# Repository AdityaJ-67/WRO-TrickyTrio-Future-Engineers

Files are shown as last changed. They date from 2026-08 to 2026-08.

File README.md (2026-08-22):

<h1 align="center">Tricky Trio &middot; WRO 2026 Future Engineers</h1>

<!-- TODO: add a wide hero photo of the finished robot on the mat -->

---

## Table of Contents

1. [The Team](#1-the-team)
2. [Design Philosophy](#2-design-philosophy)
3. [Components](#3-components)
4. [Mobility and Mechanical Design](#4-mobility-and-mechanical-design)
5. [3D Models and Printed Parts](#5-3d-models-and-printed-parts)
6. [Power and Sensor Architecture](#6-power-and-sensor-architecture)
7. [Software Architecture](#7-software-architecture)
8. [Parking Strategy](#8-parking-strategy)
9. [Videos](#9-videos)
10. [Acknowledgements](#10-acknowledgements)

---

## Documentation Map

Detailed engineering documentation lives beside the work it describes.

| Topic | Document |
|---|---|
| Mobility and mechanical design, torque reasoning, trade-offs | [`models/mechanical-design.md`](models/mechanical-design.md) |
| Power budget, sensor selection and placement, calibration, failure points | [`schemes/power-and-sensors.md`](schemes/power-and-sensors.md) |
| Software architecture, flowcharts, obstacle strategy, testing | [`src/software-architecture.md`](src/software-architecture.md) |
| Constraints, trade-offs and risk analysis | [`other/engineering-journal/design-decisions.md`](other/engineering-journal/design-decisions.md) |
| How the subsystems work together | [`other/engineering-journal/systems-thinking.md`](other/engineering-journal/systems-thinking.md) |
| Every problem we hit and what we changed | [`other/engineering-journal/iteration-log.md`](other/engineering-journal/iteration-log.md) |
| Test records and calibration measurements | [`other/engineering-journal/test-logs.md`](other/engineering-journal/test-logs.md) |
| Building this robot from scratch | [`REPRODUCING.md`](REPRODUCING.md) |
| Line by line code walkthrough | [`other/code-explained.md`](other/code-explained.md) |
| Wiring and connection list | [`schemes/README.md`](schemes/README.md) |

---

## 1. The Team

<!-- TODO: add the photos to t-photos/ and check the filenames match -->

| | Who we are |
|---|---|
| <!-- TODO: photo --> | **Aditya Juneja**<br><br>A tenth grader with a long standing interest in computer science and robotics, Aditya was drawn to this project by the part of engineering where a plan on paper turns into something that actually moves. Away from the workshop he plays football, competes in track and field, and will usually be found teaching himself something new. |
| <!-- TODO: photo --> | **Ishayu Datta**<br><br>Ishayu is in tenth grade and came to the team through an interest in engineering, particularly in understanding why a design works rather than simply accepting that it does. Outside school he swims and plays guitar. |
| <!-- TODO: photo --> | **Sarjas Gauhar Singh**<br><br>Robotics and computer science are what pulled Sarjas into the project, though the hands on building is the part he enjoys most. Also in tenth grade, he plays guitar in bands and plays football. |
| <!-- TODO: photo --> | **Coach**<br><br>*To be filled in.* |

<p align="center">
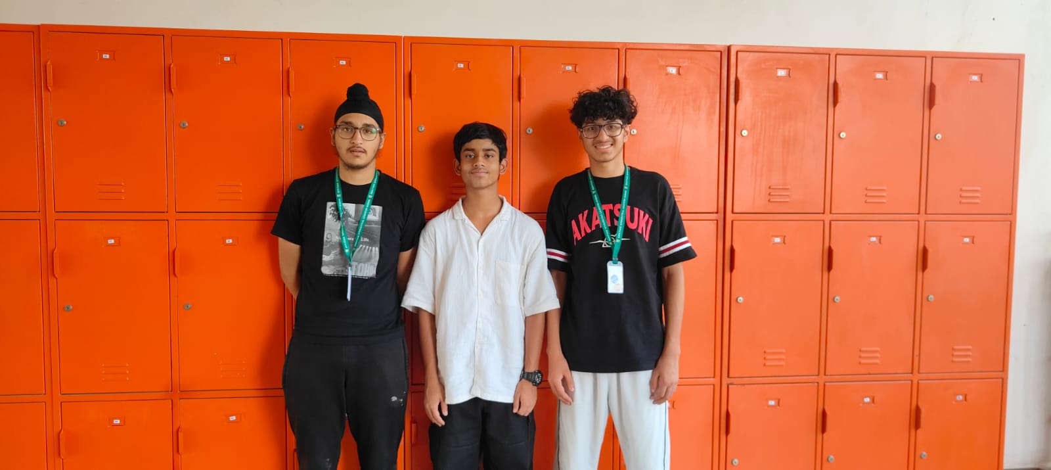
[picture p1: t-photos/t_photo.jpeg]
  
  &nbsp;
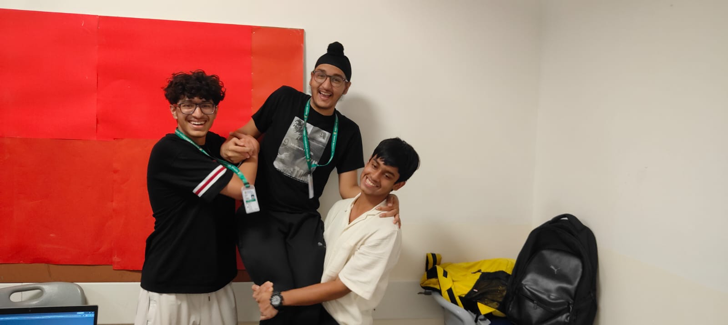
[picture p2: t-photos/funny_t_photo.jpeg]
  
</p>

**Country:** India &nbsp;&nbsp;&middot;&nbsp;&nbsp; **Team photos:** [`t-photos/`](t-photos/)

### What We Learned

**CAD and 3D design.** We designed the chassis, the steering assembly, the motor mount,
the battery holder and the wheels ourselves in Fusion 360, then printed and reprinted
them. Learning to design a part that can actually be printed, with the right tolerances
for a bearing or a screw, took several attempts per part.

**Electrical wiring and soldering.** We went from loose jumper wires to a planned
connection list and a proper PCB layout.

**Software architecture.** Writing code that a teammate can read months later turned
out to be a separate skill from writing code that works. We ended up splitting the
system into modules that each do one job, so a change to how the camera works cannot
break how the robot steers.

**Working as a team.** Three people editing the same project needed version control,
clear ownership of each subsystem, and the discipline to write down decisions instead
of remembering them.

---

## 2. Design Philosophy

Four principles we set before writing any code, and kept to. Every one of them exists
because of a specific problem we expected to hit.

**Split the work by timing requirement, not by convenience.**
The Raspberry Pi runs Linux, which is not a real time operating system. A background
process, a filesystem write or a Wi-Fi interrupt can stall a Python loop for tens of
milliseconds. That is invisible when you are processing a photo, and disastrous when a
servo is waiting for its next pulse. So the rule became: anything with a deadline runs
on the Pico, anything that needs to think runs on the Pi. The cost is a serial link
between them and the discipline of keeping a clear interface. What we get back is a
steering loop that cannot be interrupted by the camera.

**Make every module testable without the robot.**
Hardware is slow to test, easy to break, and often unavailable when you want to work.
So every file in this project runs a self test on a laptop with nothing plugged in. The
microcontroller modules are written so their hardware imports fail harmlessly off the
board, which leaves the maths behind them importable. This is why we could debug the
steering geometry and the orientation conversion weeks before the chassis was finished,
and why a change to one module tells us immediately if it broke another.

**Keep decisions in tables, not buried in conditionals.**
The robot's entire competition behaviour is one table of states and events. Anyone can
read what the robot does in each situation without following code paths through nested
if statements. When we improve how the robot detects a corner, we change how that event
is produced and the behaviour table never needs to know.

**Prefer something tunable over something optimal.**
A competition venue is a bad place to tune anything complicated. Where we had a choice
between a more sophisticated algorithm with several interacting constants and a simpler
one with a single gain, we took the simpler one. Being able to adjust the robot
confidently between rounds is worth more than a theoretically better response we cannot
reason about under pressure.

---

## 3. Components

<!-- TODO: add photos to v-photos/Components/ and fill any blank values.
     Blanks are values we have not measured or confirmed from a datasheet yet.
     Verify the filled figures against your own parts before relying on them. -->

### Raspberry Pi 3 Model B

<!-- TODO: photo -> v-photos/Components/pi3.jpg -->

**What it does.** Runs the camera and everything that needs to think: the vision
pipeline that finds traffic signs and parking markers, the navigation engine that
decides speed and steering, and the state machine that tracks what the robot is doing.
Chosen because computer vision needs an operating system, a filesystem and real RAM,
none of which a microcontroller has.

| Specification | Value |
|---|---|
| Processor | Broadcom BCM2837, quad core Cortex-A53 |
| Clock speed | 1.2 GHz |
| RAM | 1 GB LPDDR2 |
| Supply voltage | 5 V |
| Recommended supply current | 2.5 A |
| GPIO logic level | 3.3 V |
| Camera interface | 15 pin CSI-2 |
| Measured current draw, running vision | |

### Raspberry Pi Pico 2 W

<!-- TODO: photo -> v-photos/Components/pico.jpg -->

**What it does.** Runs everything with a deadline: the motor, the steering servo, the
wheel encoder and all six sensors. It also holds the safety watchdog, which stops the
robot if the Pi goes quiet for half a second.

| Specification | Value |
|---|---|
| Microcontroller | RP2350 |
| Cores | Dual Cortex-M33 |
| Clock speed | 150 MHz |
| SRAM | 520 KB |
| Flash | 4 MB |
| VSYS input range | 1.8 to 5.5 V |
| Logic level | 3.3 V, not 5 V tolerant |
| Measured current draw | |

### Camera Module 3

<!-- TODO: photo -> v-photos/Components/camera.jpg -->

**What it does.** The only sensor that can tell red from green, and the only one that
sees far enough ahead to plan a manoeuvre rather than react to one. It also finds the
magenta parking markers and the black wall.

| Specification | Value |
|---|---|
| Sensor | Sony IMX708 |
| Full resolution | 11.9 MP, 4608 x 2592 |
| Resolution used | 640 x 480 |
| Horizontal field of view | 66 degrees, standard lens |
| Focus | Autofocus |
| Connector | 15 pin FPC |
| Mounting height above mat | |
| Mounting angle | |

### GA12-N20 Gear Motor with Encoder

<!-- TODO: photo -> v-photos/Components/motor.jpg -->

**What it does.** Single drive motor on the rear axle. The built in encoder is the
important part: it lets us measure how far the wheels have actually turned, rather than
assuming the motor did what we asked. Without it the robot cannot tell that it is
stuck.

| Specification | Value |
|---|---|
| Rated voltage | 6 V |
| Encoder pulses per motor revolution | 7 |
| Gear ratio | |
| No load speed at the output shaft | |
| Stall torque | |
| Stall current | |
| Pulses per wheel revolution | |

### MG90S Servo

<!-- TODO: photo -> v-photos/Components/servo.jpg -->

**What it does.** Turns the front wheels through the Ackermann linkage. Metal geared,
so the gear train survives clipping a wall, which is what destroys plastic geared
servos.

| Specification | Value |
|---|---|
| Operating voltage | 4.8 to 6.0 V |
| Stall torque | 1.8 kg-cm at 4.8 V, 2.2 kg-cm at 6 V |
| Operating speed | 0.1 s per 60 degrees at 6 V |
| Gear material | Metal |
| Control signal | 50 Hz PWM |
| Pulse width range used | 1000 to 2000 microseconds |
| Steering range achieved | |

### DRV8833 Motor Driver

<!-- TODO: photo -> v-photos/Components/drv8833.jpg -->

**What it does.** Sits between the Pico and the motor. The Pico's pins can supply a few
milliamps; the motor needs hundreds. The driver takes a logic level signal and switches
the battery voltage across the motor, and it controls direction as well as speed.

| Specification | Value |
|---|---|
| Motor supply range | 2.7 to 10.8 V |
| Continuous current per channel | 1.5 A |
| Peak current per channel | 2 A |
| Logic input | 3.3 V compatible |
| PWM frequency used | 20 kHz |
| Control method | PWM on one input sets direction and speed |

### VL53L0X Time of Flight Sensor

<!-- TODO: photo -> v-photos/Components/vl53l0x.jpg -->

**What it does.** Four of these measure distance by timing a laser pulse. One faces
forward for corner detection, two face the forward diagonals for lane position, and one
faces backward. Unlike ultrasonic sensors they are unaffected by sound, and unlike the
camera they work regardless of colour.

| Specification | Value |
|---|---|
| Quantity | 4 |
| Measuring range | 30 to 2000 mm |
| Emitter | 940 nm VCSEL laser |
| Field of view | 25 degrees |
| I2C address | 0x29, fixed |
| Supply voltage | 3.3 V |
| Default timing budget | 33 ms per reading |
| Mounting angles | 0, minus 45, plus 45, 180 degrees |

### TCA9548A I2C Multiplexer

<!-- TODO: photo -> v-photos/Components/tca9548a.jpg -->

**What it does.** Solves a specific problem: every VL53L0X has the same fixed I2C
address, and so does the colour sensor. Put two on one bus and both answer at once. The
multiplexer connects one channel at a time, so each sensor gets the bus to itself.

| Specification | Value |
|---|---|
| Channels | 8 |
| Channels used | 6 |
| Address range | 0x70 to 0x77 |
| Address used | 0x70 |
| Supply voltage | 3.3 V |
| Bus speed used | 400 kHz |

### BNO085 IMU

<!-- TODO: photo -> v-photos/Components/bno085.jpg -->

**What it does.** Tells us which way the robot is pointing. This is how we know a
90 degree turn is finished, and how we hold a straight line between corners. It runs
sensor fusion on its own processor, so it hands over a finished orientation rather than
raw values to filter ourselves.

| Specification | Value |
|---|---|
| Sensors | 3 axis accelerometer, gyroscope and magnetometer |
| Output used | Rotation vector, as a quaternion |
| Supply voltage | 3.3 V |
| I2C address | 0x4A, or 0x4B if the jumper is bridged |
| Multiplexer channel | 2 |
| Polling rate used | 20 Hz |
| Heading accuracy | |

### TCS34725 Colour Sensor

<!-- TODO: photo -> v-photos/Components/tcs34725.jpg -->

**What it does.** Reads the colour of the mat directly underneath the car, which is how
we detect the orange and blue corner lines. Its built in infrared filter is why it stays
accurate while four infrared distance sensors are firing next to it.

| Specification | Value |
|---|---|
| Output channels | Red, green, blue and clear |
| Infrared filter | On die |
| Supply voltage | 3.3 V |
| I2C address | 0x29, fixed |
| Multiplexer channel | 1 |
| Gain options | 1x, 4x, 16x, 60x |
| Gain used | 4x |
| Integration time used | 50 ms |
| Mounting height above mat | |

### Mini560 Buck Converter

<!-- TODO: photo -> v-photos/Components/mini560.jpg -->

**What it does.** Steps the battery voltage down to a steady 5 V for the Pi, the Pico
and the servo. A buck converter rather than a linear regulator because it wastes far
less energy as heat, which matters when the Pi alone can draw over two amps.

| Specification | Value |
|---|---|
| Input voltage range | 4.5 to 20 V |
| Output voltage | 5 V |
| Maximum output current | 5 A |
| Efficiency | Up to 97 percent |
| Measured output under full load | |

### Battery

<!-- TODO: photo -> v-photos/Components/battery.jpg -->

**What it does.** Powers everything. Chosen for a high discharge rating, since the peak
draw when the servo hits full lock while the motor is accelerating is several times the
average.

| Specification | Value |
|---|---|
| Chemistry | 2S1P LiPo |
| Nominal voltage | 7.4 V |
| Capacity | 1500 mAh |
| Discharge rating | 35C |
| Stored energy | 11.1 Wh |
| Mass | |
| Measured run time | |

---

## 4. Mobility and Mechanical Design

### Chassis

| Property | Value | Why |
|---|---|---|
| Length | 15.0 cm | The parking slot is 1.5 times the robot length, so every centimetre of car costs 1.5 cm of slot. Short is safe. |
| Width | 10.5 cm | The lane is 100 cm wide. Narrow enough to pass a sign with margin either side. |
| Drive | Single motor, rear axle | The rules require the drive wheels to be physically connected. One motor through a gearbox satisfies this and removes differential speed error. |
| Steering | Ackermann, front axle, one servo | Required by the category focus on kinematics other than differential drive. |

### Why This Motor

The GA12-N20 was chosen for three reasons, in order of weight.

**The built in encoder was the deciding factor.** It lets us measure actual wheel
rotation instead of assuming that PWM duty maps cleanly to speed. Without odometry we
cannot detect a stalled robot, and stall detection is what triggers our recovery
behaviour. A robot that is wedged against a wall and does not know it will sit there
until the round ends.

Second, the integrated gearbox fits a package small enough for a 15 cm chassis. Third,
it runs at 6 V, matching the rest of the low voltage system.

**Torque and speed reasoning.** Theoretical top speed follows the relation between
wheel circumference and output shaft revolutions per minute. That figure ignores load,
rolling resistance and battery sag, so we treat it as an upper bound rather than a
target, and tune the operating speed experimentally instead.

<!-- TODO: measure these on the bench and fill them in. Do not estimate.
| Measurement | Value |
|---|---|
| Measured top speed, wheels off the ground | |
| Measured top speed, on the mat | |
| Lowest PWM percentage that actually moves the robot | |
| Time to travel 1 m from standstill | |
| Measured turning radius at full lock | |
-->

### Ackermann Steering

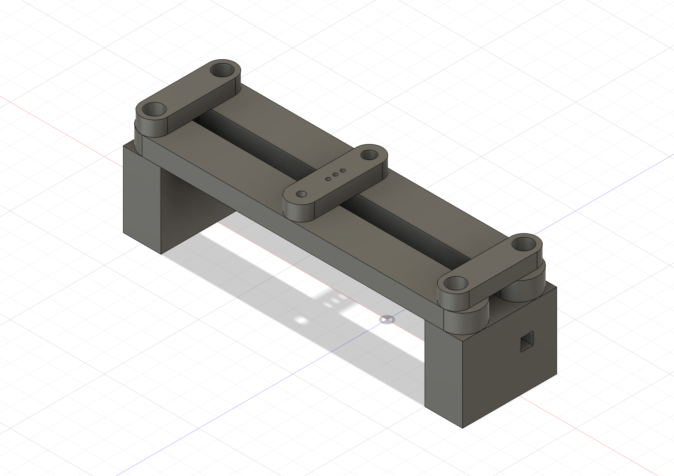
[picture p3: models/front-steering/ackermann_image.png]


We use an **Ackermann steering geometry** on the front axle, driven by a single servo
through a track rod.

The problem Ackermann solves is that when a car turns, the inside wheel travels a
tighter circle than the outside wheel. If both front wheels were held parallel, one of
them would have to scrub sideways through every corner, which wastes energy, wears the
tyre and makes the turn unpredictable. Ackermann geometry angles the steering arms so
the inside wheel turns through a **larger** angle than the outside one, letting both
wheels roll cleanly around a common centre.

For this robot that matters for two reasons. The corners are tight, so the difference
between the two wheel angles is significant rather than negligible. And our odometry
comes from the driven rear wheels, so anything that makes the front wheels scrub
introduces error into how far we think we have travelled.

The full assembly is in
[`models/front-steering/`](models/front-steering/) as a Fusion 360 file.

### Steering Control

The servo angle is converted to a pulse width from a calibrated centre position, with
three deliberate safety features.

The centre position is calibrated per build, because no two linkages sit neutral at the
same pulse width. A direction constant flips the sign if the servo is mounted mirrored,
so a mounting error is fixed with a constant rather than by negating in the code, and
the sign convention stays identical on both controllers.

Most importantly, the angle is clamped to plus or minus 30 degrees before conversion,
and the resulting pulse is clamped again to a safe range. A runaway command therefore
cannot drive the servo into the steering linkage and stall it. A stalled MG90S draws
over an amp and destroys its own gears in about a minute.

---

## 5. 3D Models and Printed Parts

Every structural part on this robot was designed by us and printed or fabricated in
house. Source files are in [`models/`](models/), organised by subsystem, each with the
CAD file and a render.

### Front Steering Assembly



Holds the two front wheels, the steering knuckles and the track rod that connects them
to the servo horn. The geometry of the steering arms is what produces the Ackermann
angle difference described above, so this part had the tightest tolerances of anything
we designed.

[`Ackerman System vinfinity.f3d`](models/front-steering/Ackerman%20System%20vinfinity.f3d)

### Rear Drive Mount

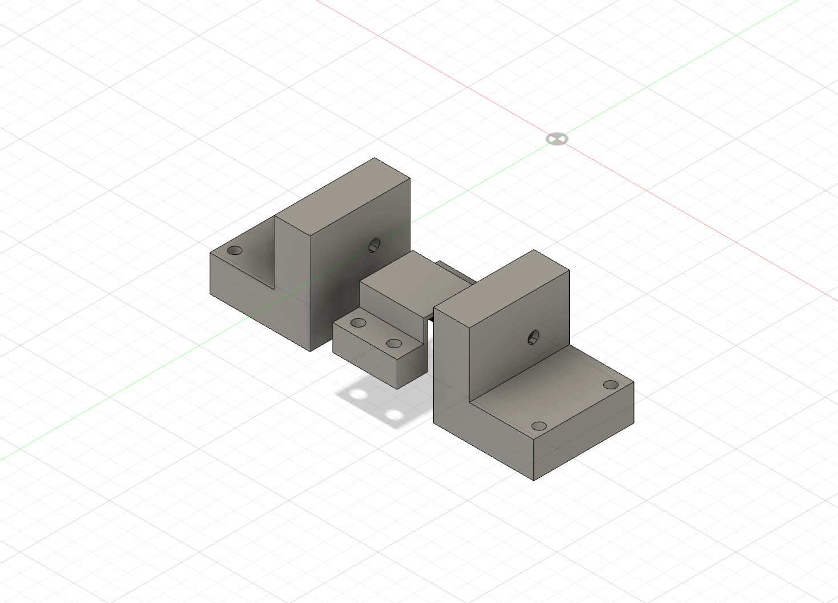
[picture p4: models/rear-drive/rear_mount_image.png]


Holds the GA12-N20 motor rigidly in line with the rear axle. Rigidity matters more than
it looks: any flex here shows up as inconsistent odometry, because the encoder counts
motor revolutions while the wheel is what actually moves the robot.

[`rear_motor_mount.step`](models/rear-drive/rear_motor_mount.step)

### Wheels

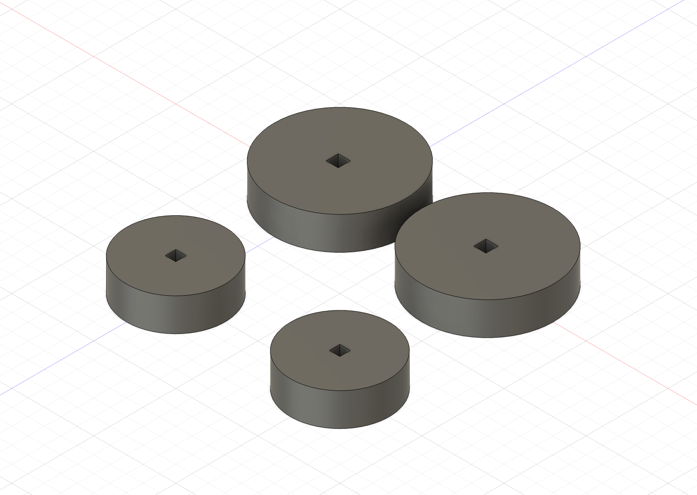
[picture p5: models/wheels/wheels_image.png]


Designed to a diameter that keeps the chassis low while giving enough ground clearance
for the mat. Wheel diameter feeds directly into every distance the robot calculates, so
this dimension is measured under load rather than taken from the model.

[`wheels.f3d`](models/wheels/wheels.f3d)

### Chassis Body

The body is printed in four sections so each fits the print bed and can be replaced on
its own without reprinting the whole car.

| Part | Render | Files |
|---|---|---|
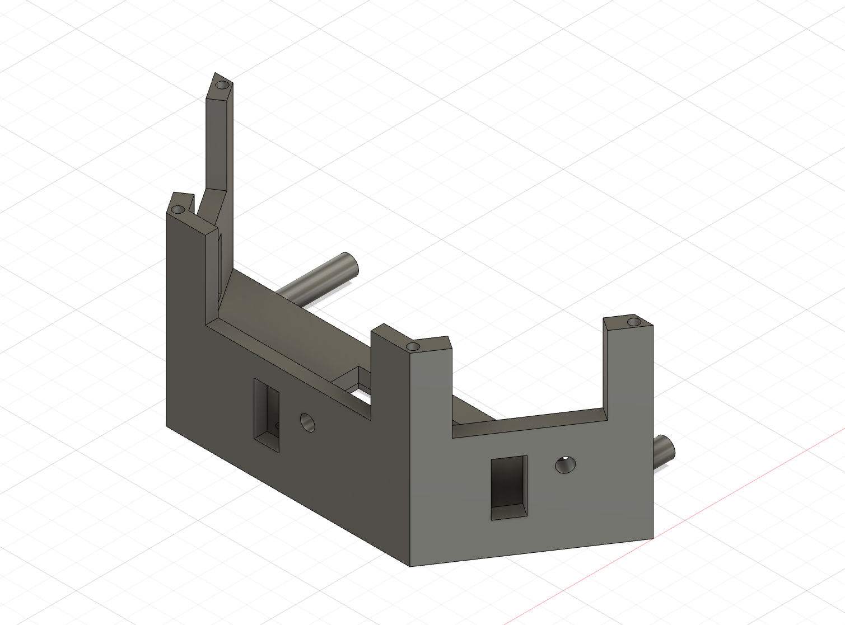
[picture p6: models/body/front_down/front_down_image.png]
| Front lower |  | [`front down.stl`](models/body/front_down/front%20down.stl) |
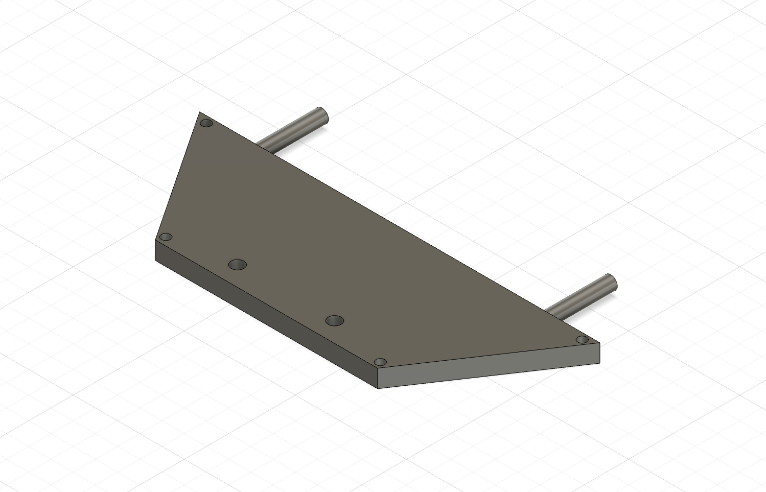
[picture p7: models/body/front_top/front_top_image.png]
| Front upper |  | [`front top.stl`](models/body/front_top/front%20top.stl) |
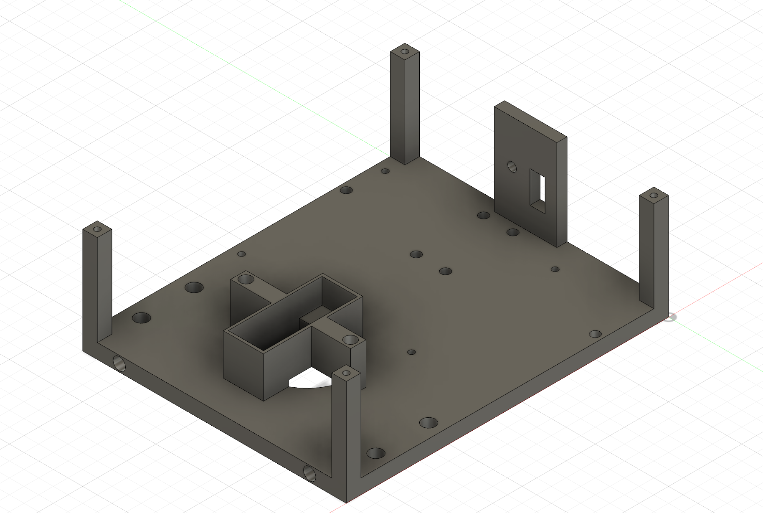
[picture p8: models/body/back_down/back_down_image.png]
| Rear lower |  | [`back down.stl`](models/body/back_down/back%20down.stl) |
| Rear upper | <!-- TODO: add back_top image and STL --> *to be added* | [`back_top/`](models/body/back_top/) |

### Camera Mount

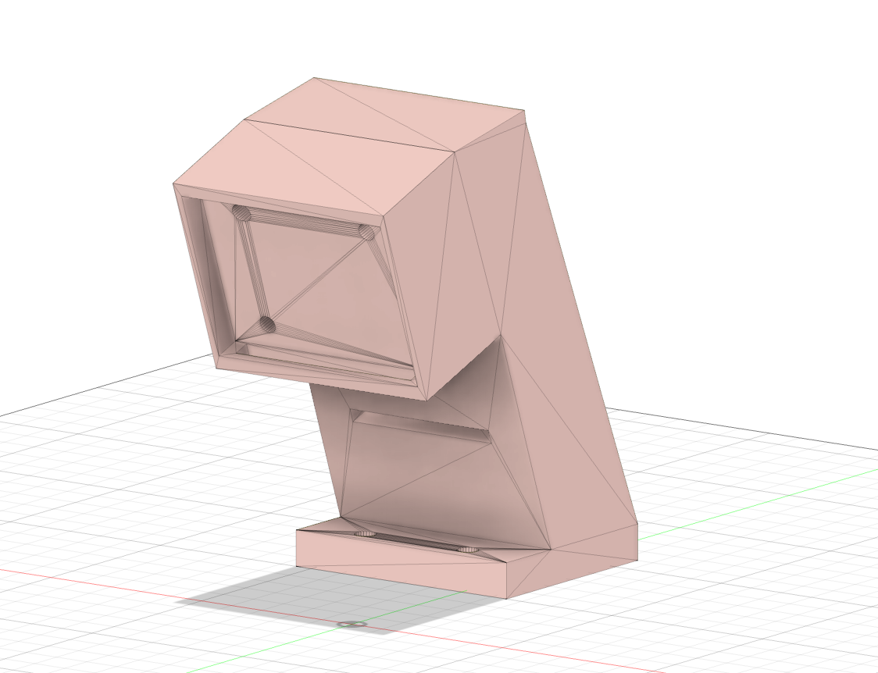
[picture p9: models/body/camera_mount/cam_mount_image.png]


Holds the camera at the front of the car, above the chassis. Height is the point of
this part: the further up the camera sits, the earlier it sees a traffic sign and the
more room the robot has to plan a way around it. The mount is rigid because the
distance estimate depends on how tall a sign appears in the frame, so a camera that
sags or vibrates reports the wrong range.

[`camera_mount.stl`](models/body/camera_mount/camera_mount.stl)

### Battery Mount

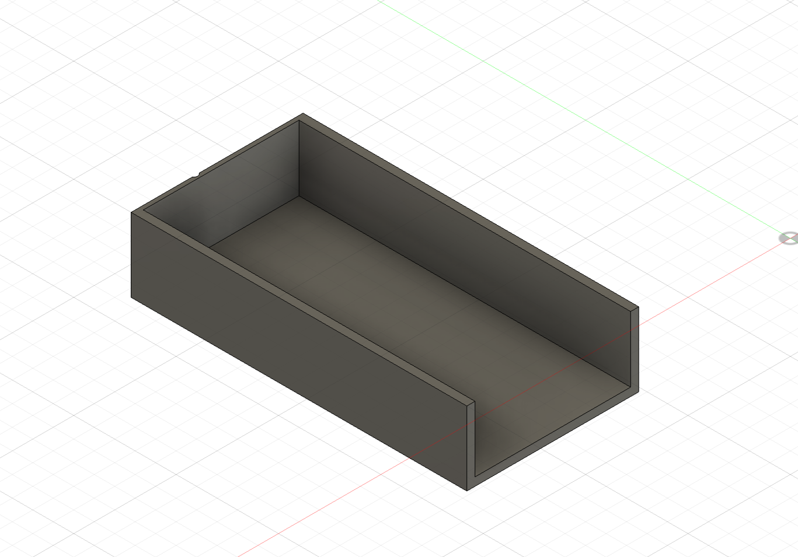
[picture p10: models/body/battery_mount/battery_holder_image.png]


Holds the LiPo low and central. Battery position affects weight distribution, which
affects how much grip the driven rear wheels have, so it is mounted as low as the
chassis allows.

[`battery_mount.stl`](models/body/battery_mount/battery_mount.stl)

<!-- TODO: worth adding if you have the information
| Print setting | Value |
|---|---|
| Material | |
| Layer height | |
| Infill | |
| Supports | |
-->

---

## 6. Power and Sensor Architecture

Wiring diagrams are in [`schemes/`](schemes/), with the complete master connection list
in [`schemes/README.md`](schemes/README.md).

### Power Budget

| Consumer | Typical | Peak | Notes |
|---|---|---|---|
| Raspberry Pi 3 | ~700 mA | ~2.5 A | Peaks during vision processing |
| MG90S servo | ~200 mA | ~1.5 A | Peak at stall or full lock |
| GA12-N20 motor | ~150 mA | ~800 mA | Peak at stall |
| Pico 2 W and sensors | ~150 mA | ~200 mA | Six I2C devices on the 3.3 V rail |
| **Total** | **~1.2 A** | **~5 A** | |

The peak figure is the one that matters. The Pi browns out and reboots if the 5 V rail
sags, and it sags exactly when the servo slams to full lock, which is precisely when
the robot is doing something difficult. Our mitigations are a 100 uF electrolytic
capacitor across the motor driver's supply pins at the driver itself, and a 0.1 uF
ceramic capacitor across the motor terminals to suppress brush noise.

### Sensor Placement



| Sensor | Quantity | Placement | Why here |
|---|---|---|---|
| Camera Module 3 | 1 | Front, elevated | Height gives earlier sight of signs, and it is the only sensor that distinguishes colour |
| VL53L0X | 1 | Front, 0 degrees | Corner confirmation and collision avoidance |
| VL53L0X | 2 | Plus and minus 45 degrees, flanking the camera | Lane position and corner geometry |
| VL53L0X | 1 | Rear, 180 degrees | Parking and reversing clearance |
| BNO085 | 1 | Rear of centre, mounted flat | Heading for turn completion and straight line hold |
| TCS34725 | 1 | Underside of the nose, below the camera mount | Corner line detection |

**The nose is a trapezoid**, and that shape exists to serve the sensors. Its three
faces each carry one distance sensor mounted perpendicular to that face, which is what
produces the 0 and plus or minus 45 degree angles without needing any brackets or
shims. A sensor sitting flat against a flat face is also far easier to align
repeatably than one held at an angle, and alignment matters because the readings are
compared against each other.

**The colour sensor sits at the very front, under the camera mount.** Putting it there
rather than under the middle of the car means the robot crosses a corner line with its
sensor before it crosses it with its wheels, which buys reaction time at exactly the
moment it is needed. It also shares the camera mount, so both sensors move together if
the mount is ever adjusted.

**The IMU sits toward the rear.** Heading is a property of the whole vehicle rather than
of a point on it, so a yaw reading is the same wherever the sensor is bolted. That frees
the IMU to go wherever there is flat, rigid space, which on this chassis is behind the
drive assembly, well away from the crowded nose.

**Why 45 degrees and not 90?** This is the placement decision we spent longest on.
Sensors pointing straight out to the sides tell you the lane width, but they only see a
corner once you are already level with it, which is too late to plan a turn. At 45
degrees they watch the forward diagonals, so an approaching inner wall shows up while
there is still room to react.

### Why a Multiplexer

Every VL53L0X ships with the same fixed I2C address, and so does the colour sensor. Put
two on one bus and both answer at once, and nothing in software can separate them.

There are two ways out. One is to pulse each sensor's shutdown pin at boot to bring
them up one at a time and reassign addresses. The other is to switch the bus. We chose
the TCA9548A multiplexer because it needs no extra GPIO pin per sensor and no boot time
sequencing that can fail silently.

| Multiplexer channel | Device |
|---|---|
| 0 | VL53L0X front |
| 1 | TCS34725 colour |
| 2 | BNO085 IMU |
| 3 | VL53L0X left |
| 4 | VL53L0X right |
| 5 | VL53L0X rear |

The cost is that reads are sequential: switch channel, talk, switch channel, talk. A
full sweep of four distance sensors costs about 132 ms, which is why the Pico applies
commands every 20 ms but sweeps sensors only every 150 ms. A single speed loop would
have delayed every motor command by the length of a sensor sweep.

---

## 7. Software Architecture

```
   +---------------- Raspberry Pi 3 ----------------+   +---- Pico 2 W ----+
   |                                                |   |                  |
   |  camera --> vision --> signs, wall, slot --+   |   |  motionController|
   |                                            |   |   |    servo         |
   |  robot_state --> mission --> navigation ---+   |   |    motor driver  |
   |                             (HOW to drive) |   |   |                  |
   |                          state machine ----+---+---+--> "45,23"       |
   |                          (WHAT we are doing)   |   |                  |
   |                                                |   |  sensorManager   |
   |  robot_state <---------------------------------+---+-- "S,480,230..." |
   +------------------------------------------------+   +------------------+
```

Each frame runs these seven steps, in this exact order.

| Step | What happens | Module |
|---|---|---|
| 1 | Capture a frame | `main.py` |
| 2 | Detect signs, wall and parking markers | `vision_test.py` |
| 3 | Read the newest robot state from the Pico | `main.py` |
| 4 | Ask which challenge is active | `mission_manager.py` |
| 5 | Decide **how** to drive, meaning speed and steering | `navigation_engine.py` |
| 6 | Decide **what** we are doing, and restrain the command | `state_machine.py` |
| 7 | Send the final command over UART | `main.py` |

**The separation that makes this work.** Navigation decides how to drive. The state
machine decides what we are doing, and it may only restrain navigation's request, never
invent one of its own. Cornering caps the speed lower than the straights. Recovery caps
it lower still. Finishing caps it to zero.

Only the coordinator writes to the serial port, and it writes only the state machine's
output, so there is exactly one place in the whole system where a command can reach the
wheels.

### The State Machine

**Twelve states, seventeen events, thirty transitions, three missions.**

The critical design choice is that detecting what happened is separate from deciding
what to do about it. One function turns sensor readings into named events, and it is
the only place that knows about millimetres and degrees. A separate table maps each
state and event to the next state, and that table contains no numbers at all.

Row order within the table is priority. When a wall and a sign are both visible, the
wall wins, and that is a line you can point at rather than a consequence of which if
statement happened to come first.

States: `WAIT_FOR_START`, `INITIALISE`, `FOLLOW_COURSE`, `APPROACH_PILLAR`,
`PASS_PILLAR`, `RECENTER`, `TURN_CORNER`, `SEARCH_PARKING`, `ALIGN_PARKING`,
`ENTER_PARKING`, `RECOVERY`, `FINISHED`.

### Vision Pipeline

Cost per frame is linear in the number of pixels and linear in the number of contours
found, and the pixel count is fixed by the processing width rather than the camera
resolution. The pipeline measures 0.32 ms per frame on a development laptop, which
means the camera frame rate is the ceiling rather than the code.

| Stage | Detail |
|---|---|
| Region of interest | Top 35 percent discarded, since only ceiling and lights live up there |
| Downscale | Detection runs at 320 pixels wide, drawing stays at full resolution |
| Colour threshold | Red needs two hue ranges because hue wraps around zero |
| Morphology | Open to remove speckle, close to fill glare holes |
| Contour filter | Area, aspect ratio and fill ratio together |

**Why the fill ratio matters.** Taking the largest contour locks onto a red jacket in
the audience or a stripe of glare on the mat. A real traffic sign fills its bounding
box, and scattered reflections do not. A candidate must pass area, aspect ratio and
fill ratio before it is believed.

**Distance from a single camera.** Signs are a known 10 cm tall, so the ratio of real
height to pixel height gives range without a stereo rig.

---

## 8. Parking Strategy

The parking lot is bounded by two magenta elements measuring 20 by 2 by 10 cm. The slot
is 20 cm wide and 1.5 times the robot's length, which for our 15 cm car means 22.5 cm.

### Magenta Against Red

Magenta sits immediately below red on the hue circle. Our original upper red band
started low enough that it **swallowed the magenta markers entirely**, and the robot
saw the parking lot as a giant traffic sign and tried to pass it on the right. The red
band now starts higher, which costs nothing because red's main band sits at the other
end of the scale.

### Aiming at the Gap

The vision module returns the midpoint between the markers' inner edges, which is the
slot itself rather than either marker. Both markers must be visible before the robot
commits, because you cannot aim at a gap you can only half see.

The sequence is `SEARCH_PARKING`, then `ALIGN_PARKING`, then `ENTER_PARKING`, then
`FINISHED`.

### Two Problems This Sequence Taught Us

**We were watching the wrong sensor.** Our first version stopped when the rear distance
sensor read close. But the camera faces forward, so the slot is only visible while
driving at it, meaning the robot enters nose first and the rear sensor is pointed back
at the open mat it came from. It never triggered, and the robot stopped on a timeout
rather than on arrival.

**The stop was then physically unreachable.** Navigation performs an emergency stop at
150 mm, but the parking trigger sat at 120 mm, so the robot froze before it could ever
reach its own trigger. The fix was a minimum speed for the entry phase, together with a
threshold below the emergency stop line, and a check that enforces that ordering so it
cannot silently break again.

---

## 9. Videos

<!-- TODO: replace with real links. Each video must show at least 30 seconds of
     autonomous driving, and one is required for each challenge. -->

| Round | Link |
|---|---|
| Open Challenge | *YouTube URL* |
| Obstacle Challenge | *YouTube URL* |

Also recorded in [`video/`](video/).

---

## 10. Acknowledgements

<!-- TODO: your school, mentors and sponsors -->

Open source work we build on: OpenCV, MicroPython, and the MicroPython drivers for the
VL53L0X, BNO08x and TCS34725 sensors. We also studied the public repositories of
previous WRO Future Engineers teams. The category's culture of publishing work openly
is the reason this repository exists in the form it does.

---

<p align="center">
  <b>Team Tricky Trio</b> &middot; India &middot; WRO 2026 Future Engineers
</p>

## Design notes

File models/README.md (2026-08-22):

# Models

**Design reasoning, torque and speed calculations, trade-offs and iterations are in
[mechanical-design.md](mechanical-design.md).**

CAD source files and renders for every part we designed and fabricated ourselves.
Organised by subsystem, one folder per part, each containing the model file and an
image of it.

| Folder | Part | Format |
|---|---|---|
| [`front-steering/`](front-steering/) | Ackermann steering assembly | Fusion 360 |
| [`rear-drive/`](rear-drive/) | Motor mount for the rear axle | STEP |
| [`wheels/`](wheels/) | Wheels | Fusion 360 |
| [`body/front_down/`](body/front_down/) | Front lower chassis section | STL |
| [`body/front_top/`](body/front_top/) | Front upper chassis section | STL |
| [`body/back_down/`](body/back_down/) | Rear lower chassis section | STL |
| [`body/back_top/`](body/back_top/) | Rear upper chassis section | STL |
| [`body/camera_mount/`](body/camera_mount/) | Camera mount | STL |
| [`body/battery_mount/`](body/battery_mount/) | Battery holder | STL |

The body is split into four printed sections so each fits the print bed and can be
reprinted on its own without redoing the whole car.

`.f3d` files are Fusion 360 sources and can be edited. `.stl` files are print ready
meshes. `.step` is a neutral CAD format that most packages can open.

See the main [README](../README.md) for how each part fits into the robot and why it is
shaped the way it is.

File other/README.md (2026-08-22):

# Other

Supporting material.

| Item | Contents |
|---|---|
| [`engineering-journal/`](engineering-journal/) | Design decisions, systems thinking, iteration log, test logs |
| [`code-explained.md`](code-explained.md) | Beginner level walkthrough of every source file |

<!-- TODO: this folder is currently empty. Worth adding:

       engineering-journal.pdf   The engineering journal, covering weekly progress,
                                 sketches, prototypes that did not work, and test logs.
                                 Judges evaluate this alongside the repository.

       datasheets/               Datasheets for the components, so anyone rebuilding
                                 the robot does not have to hunt for them.

       test-logs/                Records of bench and field testing. Dates, what was
                                 tested, what the numbers were, what changed as a
                                 result.

       calibration.md            The measured values for this particular build:
                                 gear ratio, wheel diameter under load, servo centre
                                 pulse, camera field of view, and the HSV colour
                                 ranges tuned on the competition mat. -->

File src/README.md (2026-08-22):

# Source Code

**Architecture, flowcharts, obstacle strategy and the testing process are in
[software-architecture.md](software-architecture.md).**

All software for the robot, split by the controller it runs on.

| Folder | Board | Language |
|---|---|---|
| [`pi3/`](pi3/) | Raspberry Pi 3 Model B | Python 3 with OpenCV |
| [`pico/`](pico/) | Raspberry Pi Pico 2 W | MicroPython |

## Why the split

The Raspberry Pi runs Linux, which is not a real time operating system. A background
process or a filesystem write can stall a Python loop for tens of milliseconds, which is
invisible when processing an image and disastrous when a servo is waiting for its next
pulse.

So the division is by timing requirement. Anything with a deadline runs on the Pico.
Anything that needs to think runs on the Pi. The two talk over a serial link: the Pi
sends a speed and steering command, the Pico sends back its sensor readings.

## Running the tests

Every module carries a self test that runs on a laptop with no hardware attached. The
MicroPython modules are written so their hardware imports fail harmlessly off the board,
which leaves the logic behind them testable.

```
cd src/pi3
python3 navigation_engine.py --selftest
python3 state_machine.py --selftest
```

Fifteen of the sixteen modules are covered. See each folder's README for detail.

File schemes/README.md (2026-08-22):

# Electrical Components and Wiring

## Contents

1. [System Architecture](#system-architecture)
2. [Component List](#component-list)
3. [Design Rationale](#design-rationale)
4. [Master Connection and PCB Routing List](#master-connection-and-pcb-routing-list)

---

## System Architecture

Compute is split across two boards. The **Raspberry Pi 3** is the high level brain,
handling anything that needs an operating system. The **Pico 2 W** is the low level
brainstem, handling anything with a deadline.

### What the Pi 3 is responsible for

**Computer vision.** The Camera Module 3 connects directly to the Pi 3, because
processing a live video feed needs the CPU, RAM and filesystem that a microcontroller
does not have. The Pi runs the detection pipeline that finds red and green traffic
signs, the black wall, and the magenta parking markers, and estimates the distance to
each from its known real height.

**Navigation and planning.** The Pi ingests the sensor readings the Pico sends over
UART, combines them with what the camera sees, and decides how to drive. Separate
steering laws handle lane following, sign passing, cornering and parking.

**Competition behaviour.** An event driven state machine tracks what the robot is
currently doing across twelve states and three missions, and has the final say on the
command that gets sent to the Pico.

**Telemetry.** During testing the Pi prints a status block per frame and can draw the
camera view with detections overlaid, which is how the vision thresholds get tuned.

### What the Pico 2 W is responsible for

Linux is not a real time operating system. A background process, a filesystem sync or a
Wi-Fi interrupt can stall a Python loop for tens of milliseconds, which is long enough
to make steering twitchy or leave a wheel spinning unchecked. The Pico runs a dedicated
loop instead, so these functions never get starved by the vision stack.

**Sensor harvesting.** The Pico manages the TCA9548A multiplexer, opening one channel
at a time to read the four distance sensors, the IMU and the colour sensor, then
packaging the readings into a single line of text and streaming it to the Pi.

**Actuation.** It generates the 50 Hz PWM the MG90S servo needs to hold a steering
angle without jitter, and the 20 kHz PWM that drives the DRV8833. The higher frequency
is above hearing, so the motor does not whine.

**Odometry.** The GA12-N20's encoder produces thousands of pulses per minute. The Pico
counts every one on a hardware interrupt, so pulses are never dropped even while the
main loop is busy elsewhere.

---

## Component List

<!-- TODO for each component:
       1. add a photo and fix the image path
       2. fill in the electrical values
     These are the ELECTRICAL specifications. Mechanical dimensions and
     performance figures live in the main README, so each number has one home. -->

### Raspberry Pi 3 Model B



| Specification | Value |
|---|---|
| Supply voltage | |
| Typical current draw | |
| Peak current draw | |
| Logic level | |
| Interface to Pico | |
| Camera interface | |

### Raspberry Pi Pico 2 W



| Specification | Value |
|---|---|
| Supply voltage (VSYS) | |
| Typical current draw | |
| Logic level | |
| 3.3 V rail output current available | |
| PWM channels used | |
| I2C bus used | |

### Camera Module 3



| Specification | Value |
|---|---|
| Supply | |
| Connector type | |
| Cable required for Pi 3 | |
| Resolution used | |
| Frame rate used | |

### GA12-N20 Gear Motor with Encoder



| Specification | Value |
|---|---|
| Rated voltage | |
| No load current | |
| Stall current | |
| Encoder supply voltage | |
| Encoder output type | |
| Encoder pulses per motor revolution | |

### MG90S Servo



| Specification | Value |
|---|---|
| Supply voltage | |
| Idle current | |
| Stall current | |
| Signal voltage accepted | |
| PWM frequency | |
| Pulse width range used | |

### DRV8833 Motor Driver



| Specification | Value |
|---|---|
| Motor supply (VM) range | |
| Continuous current per channel | |
| Peak current per channel | |
| Logic input voltage | |
| PWM frequency used | |
| nSLEEP handling | |

### VL53L0X Time of Flight Sensor (x4)



| Specification | Value |
|---|---|
| Supply voltage | |
| Current draw, per sensor | |
| I2C address | |
| Bus speed | |
| Multiplexer channels used | |
| XSHUT handling | |

### TCA9548A I2C Multiplexer



| Specification | Value |
|---|---|
| Supply voltage | |
| I2C address | |
| Number of channels | |
| Channels used | |
| Pull-up resistors fitted | |

### BNO085 IMU



| Specification | Value |
|---|---|
| Supply voltage | |
| Current draw | |
| I2C address | |
| Multiplexer channel | |
| Protocol select pins (PS0, PS1) | |

### TCS34725 Colour Sensor



| Specification | Value |
|---|---|
| Supply voltage | |
| Current draw | |
| I2C address | |
| Multiplexer channel | |
| Onboard LED control | |

### Mini560 Buck Converter



| Specification | Value |
|---|---|
| Input voltage range | |
| Output voltage | |
| Continuous output current | |
| Peak output current | |
| Efficiency | |

### Battery



| Specification | Value |
|---|---|
| Chemistry | 2S1P LiPo |
| Nominal voltage | 7.4 V |
| Capacity | 1500 mAh |
| Discharge rating | 35C |
| Stored energy | |
| Measured run time | |

---

## Design Rationale

Why these specific parts, rather than the alternatives.

### Compute and Control

Splitting compute across two boards was a deliberate choice rather than a default. A
single Pi could technically run everything, including the servo and motor PWM, but the
timing problem described above makes that unreliable in exactly the moments that
matter. Offloading motor control, encoder counting and the safety cutoff to the Pico
means those functions keep running no matter how busy the Pi gets processing camera
frames. The trade is extra wiring and a UART link to keep the two boards in sync, which
we accepted in exchange for control loops that never get starved.

### Drivetrain

The GA12-N20 6 V gearmotor was chosen for its combination of small size, integrated
gearbox and onboard encoder. **The encoder is the deciding factor.** It lets the Pico
measure actual wheel rotation instead of assuming a PWM duty cycle maps cleanly to
speed, and without it the robot cannot tell that it is stalled. Stall detection is what
triggers the recovery behaviour, so a robot without odometry that gets wedged against a
wall will sit there until the round ends.

Theoretical top speed follows the relation between wheel circumference and output shaft
revolutions per minute, but that ignores load, friction and battery sag, so we treat it
as a ceiling and tune the operating PWM experimentally instead.

The DRV8833 drives it, picked over bulkier options like the L298N for its smaller
footprint and much better efficiency at the low voltages this build runs at. It handles
both direction and speed while isolating the motor's current draw from the logic pins
on the Pico.

Steering uses the MG90S servo rather than a second drive motor or a rack and pinion
setup, since a servo gives direct, repeatable angle control in a small package. Its
signal comes straight from the Pico, so steering response stays independent of whatever
the Pi is doing with the camera feed. The metal gear train also survives clipping a
wall, which is the failure mode that destroys plastic geared servos.

### Power System

The robot runs on a 7.4 V, 1500 mAh, 35C, 2S1P LiPo, giving roughly 11 Wh of stored
energy.

One deliberate choice here: the DRV8833's motor supply taps the raw battery voltage
directly, in parallel with the buck converter's input, rather than running off the
regulated 5 V rail. That gives the motor more voltage headroom, at the cost of
overdriving a 6 V rated motor if it were ever run at 100 percent duty, which is why the
PWM duty is software limited rather than left uncapped. In exchange, motor current
never passes through the regulated logic rail at all, so current spikes cannot sag the
voltage feeding the Pi, the Pico or the sensors.

The Mini560 handles the regulated 5 V side that powers the Pi 3, the Pico and the
servo. The peak draw is what sizes it: the Pi alone can pull 2.5 A, and the servo adds
up to 1.5 A at stall, which happens exactly when the robot is steering hard.

### Logic Levels

**Every sensor output runs at 3.3 V.** The RP2350 is not 5 V tolerant, with an absolute
maximum of 3.3 V plus 0.3 V on any GPIO pin. This is why the N20 encoder is supplied
from the Pico's 3.3 V rail rather than the 5 V rail. A magnetic encoder outputs at
whatever voltage supplies it, so a 5 V supply would have put 5 V logic straight into
GP12 and GP13. That fault would have worked on the bench and destroyed the
microcontroller days later, which is the hardest kind of fault to diagnose because it
looks like a software bug.

### Sensor Placement



### Distance and Environmental Sensing

Four VL53L0X time of flight sensors sit across the front and back of the chassis rather
than one, so the robot gets several simultaneous readings across its field of travel
instead of a single point measurement.

The front of the chassis is a trapezoid, and its three faces each carry one sensor
mounted perpendicular to that face. That geometry is what produces the 0 and plus or
minus 45 degree angles directly, with no brackets or shims, and a sensor sitting flat
against a flat face aligns far more repeatably than one held at an angle. The two
angled sensors therefore watch the forward diagonals and see an approaching corner
while there is still room to react.

All VL53L0X units share the same default I2C address, and so does the TCS34725, which
is a problem the moment you want more than one on a bus. Rather than reflashing each
sensor's address individually, a TCA9548A multiplexer sits between the Pico and the
sensor network, giving each device its own isolated channel. That uses six of the eight
channels, leaving two free for future additions without rewiring anything.

### Orientation and Colour Sensing

The BNO085 IMU adds orientation data that neither the encoder nor the camera can
provide on their own, and it is particularly useful mid turn, where wheel odometry
alone drifts. It runs sensor fusion on its own processor rather than handing over raw
accelerometer and gyroscope values to filter.

The TCS34725 exists so that colour detection does not depend entirely on the camera. It
gives a direct, low overhead reading that the Pico can act on quickly, while the camera
handles the spatial side of track interpretation on the Pi. Its built in infrared filter
is what keeps it stable while four infrared distance sensors are firing beside it.

It is mounted on the underside of the nose, directly below the camera mount. Sitting at
the front rather than under the middle of the car means the sensor crosses a corner line
before the wheels do, which gives the robot more time to react. Sharing the camera mount
also means the two front facing sensors stay aligned with each other.

The IMU, by contrast, sits toward the rear. Yaw is a property of the whole vehicle
rather than of a point on it, so the heading reading is the same wherever the sensor is
mounted. That let us put it where there was flat, rigid space, behind the drive assembly
and away from the crowded nose.

### Vision System

The Camera Module 3 is the primary visual sensor and the only one that can distinguish
red from green. It is also the only sensor that sees far enough ahead to plan a
manoeuvre rather than react to one.

The Pi 3 has a single 15 pin CSI connector, so the camera uses a standard 15 pin ribbon
cable. The 15 to 22 pin adapter sold for Camera Module 3 is for the newer boards with
narrower connectors and does not fit a Pi 3.

---

## Master Connection and PCB Routing List

> Header pins referenced below (2/4 = 5V, 6 = GND, 8 = GPIO14/TXD, 10 = GPIO15/RXD)
> are identical across all 40-pin Raspberry Pi boards.

### 1. Power Distribution Bus
- Battery Positive (+) ➡️ Mini560 IN(+) AND DRV8833 VM (Motor Power Input).
- Battery Negative (-) ➡️ Mini560 IN(-) (Establishes the main system GND rail).
- Mini560 OUT(+) [5V Rail] ➡️ Pico 2 W Pin 39 (VSYS) AND Pi 3 Pin 2/4 (5V) AND MG90S Servo Red (VCC).
  - **The N20 encoder must NOT sit on this rail.** Its A/B outputs swing to whatever voltage supplies it, and the RP2350 GPIOs are not 5V tolerant (absolute max 3.3V + 0.3V). Encoder VCC goes to the 3V3 rail below.
- Mini560 OUT(-) [GND Plane] ➡️ Pico Pin 38 (GND) AND Pi 3 Pin 6 (GND) AND Servo Brown (GND) AND Encoder GND AND DRV8833 GND. Flood the entire bottom layer of the PCB as a solid ground plane to connect these seamlessly.
- Pico Pin 36 (3V3 OUT Rail) ➡️ VCC / VIN pins of the TCA9548A, BNO085, TCS34725, and all 4x VL53L0X sensors, **plus N20 Encoder VCC and DRV8833 nSLEEP**.
  - Encoder VCC here, not on 5V, so the A/B outputs are 3.3V logic. It draws a few mA.
  - nSLEEP (labelled SLP or EEP on most breakouts) must be high or the driver stays asleep and the motor does nothing while the code reads perfectly correct. Some breakouts pull it high on-board, so check yours before adding the trace.
- **Decoupling:** 100 µF electrolytic across DRV8833 VM/GND, placed at the driver. Motor current spikes otherwise drag the shared 5V rail down far enough to reset the Pico mid-run.

### 2. High-Level Logic Interconnects
- Pico Pin 1 (GP0 / TX) ➡️ Pi 3 GPIO Pin 10 (RXD0 / GPIO 15)
- Pico Pin 2 (GP1 / RX) ➡️ Pi 3 GPIO Pin 8 (TXD0 / GPIO 14)
  - Pi 3 only: `/dev/serial0` defaults to the mini-UART, whose baud rate drifts with CPU load and corrupts bytes once the vision code is running. Set `enable_uart=1` and `dtoverlay=disable-bt` in config.txt, then confirm `ls -l /dev/serial0` resolves to **ttyAMA0**, not ttyS0.
- Camera Module 3 ➡️ Connects directly to the Pi 3's single 15-pin CSI port via a standard 15-pin ribbon cable. The 15-to-22 pin cable is for the newer boards with narrower connectors and does not fit a Pi 3. (Does not wire to the Pico 2 W.)

### 3. Sensor I2C Network
- Pico Pin 6 (GP4 / SDA) ➡️ TCA9548A SDA (add a 4.7kΩ pull-up resistor to the 3.3V trace).
- Pico Pin 7 (GP5 / SCL) ➡️ TCA9548A SCL (add a 4.7kΩ pull-up resistor to the 3.3V trace).
- TCA9548A CH0 (SD0 / SC0) ➡️ VL53L0X Distance Sensor #1 (SDA / SCL)
- TCA9548A CH1 (SD1 / SC1) ➡️ TCS34725 Color Sensor (SDA / SCL)
- TCA9548A CH2 (SD2 / SC2) ➡️ BNO085 IMU Sensor (SDA / SCL)
- TCA9548A CH3 (SD3 / SC3) ➡️ VL53L0X Distance Sensor #2 (SDA / SCL)
- TCA9548A CH4 (SD4 / SC4) ➡️ VL53L0X Distance Sensor #3 (SDA / SCL)
- TCA9548A CH5 (SD5 / SC5) ➡️ VL53L0X Distance Sensor #4 (SDA / SCL)
- Note: leave all VL53L0X XSHUT pins completely disconnected on the PCB, since they pull high naturally.

### 4. Drivetrain Control (Motors, Encoders, & Servos)
- Pico Pin 29 (GP22) ➡️ MG90S Servo Orange (Signal Pin). Bypasses the driver entirely.
- Pico Pin 11 (GP8) ➡️ DRV8833 IN1 (Motor Drive Forward PWM)
- Pico Pin 12 (GP9) ➡️ DRV8833 IN2 (held low for forward; carries the PWM for reverse)
  - A DRV8833 has no dedicated direction pin. Whichever of IN1/IN2 carries the PWM is the direction, and the duty on it is the speed. GP8 and GP9 are the two halves of PWM slice 4, so they share a frequency, which suits reverse fine since both want the same 20 kHz.
- DRV8833 OUT1 / OUT2 ➡️ GA12-N20 Motor Pin 1 & Pin 2 (Motor Power Leads)
  - Solder a 0.1 µF ceramic across the two motor terminals. Brush noise otherwise couples into the encoder lines and shows up as phantom counts that appear only under motor power.
- GA12-N20 Motor Pin 5 (Encoder A) ➡️ Pico Pin 16 (GP12)
- GA12-N20 Motor Pin 6 (Encoder B) ➡️ Pico Pin 17 (GP13)
  - Route both encoder traces away from the thick motor leads, for the same reason.

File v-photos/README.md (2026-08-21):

# Vehicle Photos

Photographs of the assembled robot.

## Required

Six photographs of the vehicle are required: from every side, from the top, and from the
bottom.

<!-- TODO: add these six, with these filenames:

       front.jpg
       back.jpg
       left.jpg
       right.jpg
       top.jpg
       bottom.jpg

     A plain background and even lighting is enough. Fill the frame with the robot.
     The bottom view matters more than it sounds: it is the one that shows the
     drivetrain, the steering linkage and the sensor mounting. -->

## Subfolders

| Folder | Contents |
|---|---|
| [`Components/`](Components/) | Individual photographs of each electronic component |
| [`build-progress/`](build-progress/) | Photographs taken during the build |

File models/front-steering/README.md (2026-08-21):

# Front Steering Assembly



The Ackermann steering assembly. Holds both front wheels, the steering knuckles, and
the track rod that links them to the servo horn.

**Why Ackermann.** When a car turns, the inside wheel follows a tighter circle than the
outside wheel. Holding both front wheels parallel would force one of them to scrub
sideways through every corner, wasting energy, wearing the tyre and making the turn
unpredictable. Ackermann geometry angles the steering arms so the inside wheel turns
through a larger angle than the outside one, letting both roll cleanly around a shared
turning centre.

That matters here for two reasons. The corners on this course are tight, so the
difference between the two wheel angles is significant rather than negligible. And our
odometry comes from the driven rear wheels, so anything that makes the front wheels
scrub introduces error into how far the robot thinks it has travelled.

This part had the tightest tolerances of anything we designed, since the steering arm
geometry is what produces the angle difference.

| File | Format | Notes |
|---|---|---|
| `Ackerman System vinfinity.f3d` | Fusion 360 | Editable source |

<!-- TODO: fill in
| Property | Value |
|---|---|
| Material | |
| Layer height | |
| Infill | |
| Steering range achieved | |
-->

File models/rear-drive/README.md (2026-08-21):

# Rear Drive Mount



Holds the GA12-N20 gear motor rigidly in line with the rear axle.

**Why rigidity matters more than it looks.** The encoder counts revolutions of the
motor shaft, but what actually moves the robot is the wheel. Any flex or play between
the two shows up as a mismatch between the distance the robot calculates and the
distance it travels. Since our navigation uses that distance to judge how far it has
gone, a soft mount quietly degrades everything downstream.

| File | Format | Notes |
|---|---|---|
| `rear_motor_mount.step` | STEP | Neutral CAD format, opens in most packages |

<!-- TODO: fill in
| Property | Value |
|---|---|
| Material | |
| Layer height | |
| Infill | |
| Fasteners used | |
-->

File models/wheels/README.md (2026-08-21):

# Wheels



Custom wheels, sized to keep the chassis low while leaving enough ground clearance for
the mat surface.

**Why the diameter is a measured value, not a design value.** Wheel diameter feeds
directly into every distance the robot calculates, because distance travelled is
revolutions multiplied by circumference. Rubber compresses under load, so the rolling
diameter is always slightly smaller than the modelled one. We measure it with the
robot's weight on the wheels and use that figure in the code, rather than taking the
number from the CAD file.

| File | Format | Notes |
|---|---|---|
| `wheels.f3d` | Fusion 360 | Editable source |

<!-- TODO: fill in
| Property | Value |
|---|---|
| Modelled diameter | |
| Measured rolling diameter, under load | |
| Material | |
| Tyre material | |
| Layer height | |
| Infill | |
-->

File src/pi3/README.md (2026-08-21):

# Raspberry Pi 3 Source

Python 3 with OpenCV. Everything here needs an operating system: the camera, the vision
pipeline, and the decisions about where to drive.

## Files

| File | What it does |
|---|---|
| `main.py` | The control loop. Coordinates the other modules and owns the serial link. Contains no decision logic of its own. |
| `camera_vision/vision_test.py` | Detects red and green traffic signs, the black wall and the magenta parking markers, and estimates the distance to each. |
| `navigation_engine.py` | Decides how to drive. Separate steering laws for lane following, sign passing, cornering and parking. |
| `state_machine.py` | Decides what the robot is currently doing, across twelve states and three missions. Has the final say on the command sent to the Pico. |
| `mission_manager.py` | Reports which challenge is active. |
| `uart_test_pi.py` | Bench tool for testing the serial link on its own. |

## The loop

Each camera frame runs the same seven steps in the same order: capture, detect, read the
robot's state from the Pico, check the mission, decide how to drive, decide what we are
doing, send one command.

The separation that makes this work is that the navigation engine decides *how* to drive
while the state machine decides *what* we are doing, and the state machine may only
restrain navigation's request rather than invent one of its own. Only `main.py` writes
to the serial port, so there is exactly one place a command can reach the wheels.

## Running it

```
python3 main.py                    competition
python3 main.py --dry-run --show   laptop: webcam and decisions, no Pico
python3 main.py --debug            one status block per frame
```

On a Raspberry Pi 3 the serial port needs moving off the mini UART first, otherwise it
corrupts bytes under processor load. See [`schemes/README.md`](../../schemes/README.md).

## Testing

```
python3 navigation_engine.py --selftest
python3 state_machine.py --selftest
```

Every module has one, and they all run with no hardware attached.

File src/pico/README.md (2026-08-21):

# Pico 2 W Source

MicroPython. Everything here has a deadline: the motor, the steering servo, the wheel
encoder and the six sensors.

## Files

| File | What it does |
|---|---|
| `main.py` | Flight program. Reads commands, drives the robot, reports sensor state. Runs automatically on power up. |
| `motionController.py` | One interface for movement: `move(speed, steering)` and `stop()`. |
| `servo.py` | MG90S steering, with clamped angle and pulse limits. |
| `drv8833.py` | Drive motor through the DRV8833. |
| `encoder.py` | Wheel odometry from the quadrature encoder, counted on an interrupt. |
| `sensors/sensorManager.py` | Gathers every sensor reading into one dictionary. |
| `sensors/distance.py` | Four VL53L0X distance sensors behind the multiplexer. |
| `sensors/imu.py` | BNO085 orientation. |
| `sensors/colour.py` | TCS34725 floor colour. |
| `uart_echo.py` | Bench tool for testing the serial link on its own. |
| `deploy.sh` | Copies everything to the board. |

## The loop

The flight program runs at two speeds on purpose. Commands are read and applied every
20 ms, because a command that waits is a robot that has already driven somewhere else.
A full sweep of the four distance sensors costs about 130 ms, so that happens on its own
slower schedule and never delays the motor.

If no command arrives for 500 ms, meaning the Pi has crashed or the cable has come
loose, the watchdog stops the robot. This is the main reason the control system is split
across two boards.

## Deploying

MicroPython has no package imports here, so every file lands flat at the board's root
regardless of the folders used in this repository.

```
./deploy.sh              copy the flight code
./deploy.sh --drivers    also copy the sensor drivers
```

<!-- TODO: the sensor drivers are not in this repository yet. The modules import
     vl53l0x, tcs34725 and bno08x by name. Without them the sensors will not read,
     though each module reports which file is missing and the robot keeps running. -->

## Testing

```
python3 -c "import servo; servo.selftest()"
```

Each module's self test runs on a laptop with no board attached.

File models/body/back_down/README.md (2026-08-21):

# Rear Lower Chassis Section



The lower rear section of the body. Carries the drive motor mount and the rear axle,
and forms the rear floor of the car.

All drive torque is reacted through this part, so it is stiff for the same reason the
motor mount is: any flex between the motor and the wheels shows up as odometry error.

| File | Format |
|---|---|
| `back down.stl` | STL, print ready |

<!-- TODO: fill in
| Property | Value |
|---|---|
| Material | |
| Layer height | |
| Infill | |
| Print time | |
-->

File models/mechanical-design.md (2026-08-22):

# Mechanical Design and Mobility

Chassis design choices, drive and steering justification, torque and speed reasoning,
and the iterations that changed the design.

Covers rubric criterion 1. Part files and renders are in the subfolders of this
directory; this document explains why they are shaped the way they are.

## Contents

1. [Design Constraints](#design-constraints)
2. [Chassis](#chassis)
3. [Drive System](#drive-system)
4. [Torque and Speed Reasoning](#torque-and-speed-reasoning)
5. [Steering System](#steering-system)
6. [Mechanical Stability](#mechanical-stability)
7. [Trade-offs](#trade-offs)
8. [Iterations](#iterations)

## Design Constraints

Every mechanical decision on this robot traces back to one of these.

| Constraint | Source | Consequence |
|---|---|---|
| Parking slot is 1.5 times the robot's length | Rule | Length is the most expensive dimension on the robot. Every centimetre of car costs 1.5 cm of slot, and the slot is bounded by walls we must not touch. |
| Drive wheels must be physically connected | Rules 11.3 and 11.5 | One motor and a gearbox. One motor per side is explicitly forbidden. |
| Lane is 100 cm wide, signs are 5 cm square | Rule | Passing a sign in a 100 cm lane needs roughly 10.75 cm of lateral clearance from our centreline, so a narrow robot has more room for steering error. |
| Track randomised each round | Rule | The chassis must be symmetric in behaviour. It has to turn as tightly clockwise as anticlockwise. |
| Camera needs height | Physics | The higher the camera, the earlier a sign is visible. This fights against keeping the centre of gravity low. |

## Chassis

| Property | Value | Reasoning |
|---|---|---|
| Length | 15.0 cm | Sets the parking slot at 22.5 cm. Shorter would be better still, but the drivetrain, steering assembly and two boards have to fit. |
| Width | 10.5 cm | With 10.75 cm of clearance needed from the centreline, a wider car eats the margin for steering error. |
| Nose shape | Trapezoid | See below. This is the most deliberate shape decision on the robot. |
| Construction | 3D printed, four body sections | Each section fits the print bed and can be replaced without reprinting the whole car. |

### Why the nose is a trapezoid

The three front distance sensors need to look straight ahead and at plus and minus 45
degrees. There are two ways to achieve that.

The first is to mount all three on a flat front face and hold two of them at an angle
with printed wedges. The second is to shape the chassis so each sensor sits flat against
a face that already points the right way.

We chose the second. A sensor bolted flat to a flat surface aligns repeatably, every
time it is removed and refitted. A sensor held at an angle by a printed wedge depends on
the wedge printing accurately, on the screw torque, and on the part not creeping.

That repeatability matters more here than it would elsewhere, because the lane following
calculation compares the left and right readings **against each other**. A couple of
degrees of error on one side biases every lane position estimate in the same direction,
and a consistent bias is far harder to notice than random noise.

The cost is a more complex print and slightly less internal volume at the front.

## Drive System

### Motor selection

We compared three options.

| Option | Torque | Encoder | Size | Verdict |
|---|---|---|---|---|
| GA12-N20 with encoder | Adequate with gearbox | Built in | Fits | **Chosen** |
| N20 without encoder | Same | None | Fits | Rejected. No odometry means no stall detection. |
| TT gearmotor | Higher | None | Too large for a 15 cm chassis | Rejected on size. |

**The encoder was the deciding factor, not the torque.** Without odometry the robot
cannot tell the difference between driving forward and being held against a wall with
the wheels slipping. Stall detection is what triggers the recovery behaviour, and a
robot that gets wedged and does not know it will sit there until the round ends. We
would have accepted less torque to keep the encoder.

### Single motor, driven rear axle

Required by rules 11.3 and 11.5, but it also removes a problem. Two motors, one per
side, differ slightly in speed even at identical commands, and our single encoder cannot
see that difference. The robot would curve gently and the odometry would report a
straight line.

## Torque and Speed Reasoning

<!-- TODO: measure the values marked below. The formulas are correct; the numbers
     are what turn this section from theory into evidence. -->

### Top speed

Wheel speed follows from motor output speed and wheel size:

```
v = pi * D * N / 60
```

where `D` is wheel diameter in metres and `N` is output shaft revolutions per minute.

| Symbol | Value | Source |
|---|---|---|
| D, wheel diameter | *measure under load* | Rubber compresses, so the rolling diameter is smaller than the modelled one |
| N, output RPM | *from motor spec* | Depends on the gearbox ratio fitted |
| v, theoretical top speed | *calculate* | |
| v, measured on the mat | *measure* | Expect this to be lower |

The theoretical figure ignores load, rolling resistance and battery sag under current
draw, so we treat it as a ceiling rather than a target and tune the operating speed
experimentally.

### Torque required

The motor has to overcome rolling resistance and accelerate the robot's mass.

```
F_total   = F_rolling + F_acceleration
F_rolling = mu * m * g
F_accel   = m * a
T_wheel   = F_total * r
```

| Symbol | Meaning | Value |
|---|---|---|
| m | Robot mass | *weigh it* |
| mu | Rolling resistance coefficient | roughly 0.015 to 0.03, rubber on a smooth mat |
| g | Gravity | 9.81 m/s squared |
| a | Target acceleration | *choose, then verify* |
| r | Wheel radius | *measure under load* |
| T_wheel | Torque needed at the wheel | *calculate* |

Then compare against what the motor can supply:

| Check | Value |
|---|---|
| Motor stall torque at the output shaft | *from spec* |
| Torque required, from above | *calculate* |
| **Margin** | *stall divided by required* |

**What the margin should be.** A ratio near 1 means the motor barely moves the robot and
will stall on any bump or against a wall. A very large ratio means the gearbox is
over-geared and top speed suffers. We are looking for enough headroom that the robot
accelerates cleanly from rest and can push out of a light collision, without giving up
the speed needed to finish three laps in time.

### The gear ratio trade-off

Gear ratio trades torque against speed directly. A higher ratio gives more torque and a
lower top speed; a lower ratio does the reverse.

Because the course is flat and the robot is light, torque is not the binding constraint.
Speed is, since three laps have to fit inside the round. But dropping the ratio too far
means the robot cannot start cleanly from rest, and cannot recover from being nudged
against a wall.

<!-- TODO: record which ratio you fitted, and whether you tried another one. If you
     tested two ratios, that comparison is exactly the "iterations affecting
     performance" the rubric asks for. -->

## Steering System

### Ackermann geometry

When a car turns, the inside wheel follows a tighter circle than the outside wheel. If
both front wheels were held parallel, one of them would scrub sideways through every
corner.

Ackermann geometry angles the steering arms so the inside wheel turns through a larger
angle than the outside one, letting both roll cleanly around a shared turning centre.

**Two reasons it matters on this robot specifically.**

The corners are tight relative to the wheelbase, so the difference between the required
inside and outside angles is significant rather than a rounding error.

Our odometry comes from the **driven rear wheels**, and anything that makes the front
wheels scrub adds drag that the encoder cannot see. The robot would think it had
travelled further than it had.

### Servo selection

| Option | Verdict |
|---|---|
| MG90S, metal geared | **Chosen.** The gear train survives clipping a wall. |
| SG90, plastic geared | Rejected. Identical size and cheaper, but the nylon gears strip on impact, and hitting a wall during testing is certain. |
| Stepper with a rack | Rejected. Heavier, needs a driver, and open loop position is worse than a servo's closed loop. |

<!-- TODO: fill in once measured
| Measurement | Value |
|---|---|
| Maximum steering angle achieved | |
| Turning radius at full lock | |
| Servo current at full lock | |
-->

### Software protection for the mechanism

The steering angle is clamped to plus or minus 30 degrees in software **before** it is
converted to a pulse width, and the resulting pulse is clamped again to a safe range.

This exists to protect the mechanism, not the code. A runaway command cannot drive the
servo into the end of the steering linkage. A stalled MG90S draws over an amp and
destroys its own gear train in about a minute.

## Mechanical Stability

**Battery placement.** The battery is the heaviest single item, and it sits low and
central. Low keeps the centre of gravity down, which reduces how much the car leans when
cornering hard. Central keeps weight distribution predictable between the axles.

**Weight over the driven axle.** The rear wheels do all the driving, so they need
enough vertical load to grip. Too much weight forward and they slip under acceleration,
which shows up as odometry error rather than as an obvious symptom.

**Camera height versus centre of gravity.** These pull in opposite directions. A higher
camera sees signs earlier, which the navigation benefits from. A higher mass raises the
centre of gravity, which hurts cornering. The camera itself is light, so the compromise
is cheap, but the mount has to be rigid rather than tall and flexible.

**Why mount rigidity matters for the sensors.** We estimate how far away a sign is from
how tall it appears in the image. A mount that sags under its own weight, or vibrates
while the motor runs, changes that apparent height and reports the wrong distance.
Because the error is systematic rather than random, averaging does not remove it.

## Trade-offs

| Decision | Chosen | Rejected | Why |
|---|---|---|---|
| Chassis length | 15 cm | Longer, easier to package | Parking slot scales at 1.5 times length |
| Nose shape | Trapezoid | Flat front with angled brackets | Sensors align repeatably against flat faces |
| Drive | One motor, rear axle | One motor per side | Rules 11.3 and 11.5, and single encoder odometry |
| Steering | Ackermann, one servo | Parallel front wheels | Parallel wheels scrub in tight corners |
| Servo | MG90S metal gear | SG90 plastic gear | Plastic gears strip on wall impacts |
| Body | Four printed sections | One piece | Any section can be reprinted alone |
| Battery position | Low and central | Rear, easier to access | Centre of gravity and weight distribution |

## Iterations

<!-- TODO: this section is where criterion 1 is won or lost. The rubric asks
     specifically for "testing or iterations affecting performance". Record every
     version of a part, what was wrong with it, and what changed.

     For each iteration, record:
       - what the problem was, observed rather than predicted
       - what you measured
       - what you changed
       - what the measurement was afterwards

     Photograph the old part next to the new one and put it in
     v-photos/build-progress/. -->

| Part | Version | Problem observed | Change made | Result |
|---|---|---|---|---|
| | | | | |

Iterations already recorded elsewhere, which belong here too once the mechanical side
has been tested:

- The steering clamp order was changed so the angle is limited before conversion rather
  than after, so the reported angle and the physical angle always agree. Recorded in
  [the iteration log](../other/engineering-journal/iteration-log.md).

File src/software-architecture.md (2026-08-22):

# Software Architecture and Obstacle Strategy

Module structure, flowcharts, the state machine and its rationale, algorithm
justification, edge case handling, and the testing and tuning process.

Covers rubric criterion 3. A beginner level walkthrough of every individual file is in
[other/code-explained.md](../other/code-explained.md).

## Contents

1. [Module Structure](#module-structure)
2. [Control Flow](#control-flow)
3. [The State Machine](#the-state-machine)
4. [Lane Following](#lane-following)
5. [Obstacle Strategy](#obstacle-strategy)
6. [Algorithm Justification](#algorithm-justification)
7. [Edge Cases](#edge-cases)
8. [Testing and Tuning](#testing-and-tuning)
9. [Metrics](#metrics)

## Module Structure

Sixteen modules, 4,071 lines, split across two controllers by timing requirement.

| Module | Board | Responsibility | Lines |
|---|---|---|---|
| `vision_test.py` | Pi | Find signs, wall and parking markers in a frame | 330 |
| `navigation_engine.py` | Pi | Decide speed and steering | 741 |
| `state_machine.py` | Pi | Decide what the robot is doing | 966 |
| `mission_manager.py` | Pi | Report the active challenge | 44 |
| `main.py` | Pi | Coordinate the above, own the serial link | 406 |
| `main.py` | Pico | Receive commands, drive, report state | 190 |
| `motionController.py` | Pico | One interface for movement | 127 |
| `servo.py` | Pico | Steering angle to pulse width | 106 |
| `drv8833.py` | Pico | Speed to motor PWM | 101 |
| `encoder.py` | Pico | Wheel odometry | 126 |
| `sensorManager.py` | Pico | Every reading in one dictionary | 217 |
| `distance.py` | Pico | Four ToF sensors behind the multiplexer | 203 |
| `imu.py` | Pico | Orientation | 185 |
| `colour.py` | Pico | Floor colour | 208 |

### The rule that produced this split

Linux is not a real time operating system. A background process can stall a Python loop
for tens of milliseconds, which is invisible when processing an image and disastrous
when a servo is waiting for its next pulse.

**Anything with a deadline runs on the Pico. Anything that needs to think runs on the
Pi.** Every module placement follows from that.

### Modularity in practice

Three rules kept the modules genuinely separate rather than nominally separate.

**One responsibility each.** `servo.py` knows about pulse widths and nothing about
traffic signs. `navigation_engine.py` knows about steering angles and nothing about
servos.

**Dependencies point one way.** Vision does not import navigation. Navigation does not
import the state machine. The state machine does not import the serial link. Only
`main.py` knows all of them exist.

**Data crosses boundaries as plain dictionaries**, not as objects with behaviour. A
sensor reading is `{"front_distance": 480}`, which any module can read without needing
the class that produced it.

## Control Flow

### The Pi control loop

```mermaid
flowchart TD
    A[Capture camera frame] --> B{Frame valid?}
    B -->|No| A
    B -->|Yes| C[vision_test.detect]
    C --> D[Convert to pillars, wall, parking slot]
    D --> E[Read newest state from Pico]
    E --> F[mission_manager: which round?]
    F --> G[navigation_engine: HOW to drive]
    G --> H[state_machine: WHAT are we doing]
    H --> I[State machine restrains the command]
    I --> J[Send speed,steering over UART]
    J --> A
```

Seven steps. Step 9 sends the **state machine's** command, never navigation's directly,
so there is exactly one place in the system where a command can reach the wheels.

### The Pico loop

```mermaid
flowchart TD
    A[Read UART buffer] --> B{Complete line?}
    B -->|Yes| C[Keep newest command only]
    B -->|No| D{Silent > 500 ms?}
    C --> E[motionController.move]
    E --> F{150 ms since last sweep?}
    D -->|Yes| G[STOP - watchdog]
    D -->|No| F
    G --> F
    F -->|Yes| H[Read all sensors]
    F -->|No| I[Sleep 20 ms]
    H --> J[Send state line to Pi]
    J --> I
    I --> A
```

**Two clocks in one loop, on purpose.** Commands are applied every 20 ms because a
command that waits is a robot that has already driven somewhere else. A full sensor
sweep costs about 132 ms, mostly the four ToF measurements, so it runs on its own slower
schedule. A single-speed loop would have added 132 ms of lag to every steering command.

## The State Machine

Twelve states, seventeen events, thirty transitions, three missions.

```mermaid
stateDiagram-v2
    [*] --> WAIT_FOR_START
    WAIT_FOR_START --> INITIALISE: START_SIGNAL
    INITIALISE --> FOLLOW_COURSE: STATE_TIMEOUT

    FOLLOW_COURSE --> TURN_CORNER: CORNER_DETECTED
    FOLLOW_COURSE --> APPROACH_PILLAR: RED_PILLAR / GREEN_PILLAR
    FOLLOW_COURSE --> RECOVERY: RECOVERY_REQUIRED
    FOLLOW_COURSE --> SEARCH_PARKING: RUN_COMPLETE

    APPROACH_PILLAR --> PASS_PILLAR: PILLAR_CLOSE
    APPROACH_PILLAR --> TURN_CORNER: CORNER_DETECTED
    APPROACH_PILLAR --> RECENTER: PILLAR_PASSED
    PASS_PILLAR --> RECENTER: PILLAR_PASSED
    RECENTER --> FOLLOW_COURSE: LANE_CENTRED

    TURN_CORNER --> RECENTER: CORNER_COMPLETE
    TURN_CORNER --> RECOVERY: STATE_TIMEOUT

    SEARCH_PARKING --> ALIGN_PARKING: PARKING_VISIBLE
    ALIGN_PARKING --> ENTER_PARKING: PARKING_ALIGNED
    ENTER_PARKING --> FINISHED: PARKED

    RECOVERY --> FOLLOW_COURSE: PATH_CLEAR
    RECOVERY --> FINISHED: RECOVERY_EXHAUSTED
    FINISHED --> [*]
```

### Rationale: why a state machine at all

Because the same sensor reading means different things in different situations.

"A wall 500 mm ahead" means a corner is coming while driving a straight. Halfway through
a corner it is just the wall being turned away from. Without a state, every module
re-derives that context independently and they disagree with each other.

### Rationale: why event driven rather than nested conditionals

The design separates **detecting** what happened from **deciding** what to do about it.

`detect_events()` is the only function that knows about millimetres and degrees. The
transition table is the only thing that knows about behaviour, and it contains no numbers
at all.

```python
State.FOLLOW_COURSE: (
    (Event.RUN_COMPLETE,      State.SEARCH_PARKING),
    (Event.RECOVERY_REQUIRED, State.RECOVERY),
    (Event.CORNER_DETECTED,   State.TURN_CORNER),
    (Event.RED_PILLAR,        State.APPROACH_PILLAR),
    (Event.GREEN_PILLAR,      State.APPROACH_PILLAR),
),
```

Three things this buys us.

**Priority is visible.** Row order is priority, so "a wall beats a sign" is a line you
can point at rather than an accident of which `if` was written first.

**Detection can change without touching behaviour.** When corner detection improves,
`detect_events` changes and the table never learns that anything happened.

**Events fire whether or not they matter.** `PATH_CLEAR` is reported every frame the way
ahead is open. `FOLLOW_COURSE` does not list it, so it is ignored. A new state can
consume an existing event without touching detection.

### Rationale: how missions gate states

The Open Challenge has no signs to dodge, so it has no `APPROACH_PILLAR` state. Rather
than writing three state machines, a table says which states each mission has and what
it does instead:

```python
MISSION_SUBSTITUTE["OPEN_CHALLENGE"] = {
    State.APPROACH_PILLAR: None,              # skip this transition
    State.SEARCH_PARKING: State.FINISHED,     # laps done means the run is over
}
```

That second line prevents a real failure. Without it, an open challenge robot would
finish three laps, be told to go and park, find no parking state, and drive forever.

### Rationale: the state machine restrains, never invents

```python
STATE_SPEED_CAP   = {TURN_CORNER: 35, RECOVERY: 30, FINISHED: 0, ...}
STATE_SPEED_FLOOR = {TURN_CORNER: 20, ENTER_PARKING: 15, ...}
```

Navigation always decides how to drive. The state machine may only limit that. `None`
means take whatever navigation asked for.

The **floor** exists because of a real deadlock. Turning towards a wall, the front sensor
keeps closing, so the emergency stop fired mid corner. A stopped robot stops turning, so
the corner never completed, so the state timed out into recovery, and recovery could not
clear because the wall was still there. Four individually correct behaviours chaining
into a dead end. The floor makes the robot creep through instead of freezing.

## Lane Following

```
offset = (right_mm - left_mm) / (right_mm + left_mm)
steering = offset * LANE_GAIN
```

More room on the right means the robot has drifted left, so it steers right.

**Why divide by the total.** It makes the result independent of lane width. One third of
the way across a 1 metre lane and one third across a 2 metre lane give the same answer,
so the robot never needs to be told the track dimensions.

**Why readings over 2000 mm are discarded.** A VL53L0X reports about 8190 mm when it sees
nothing. Fed into that formula it looks like an enormously wide lane, and the robot
steers confidently in the wrong direction.

**Why a dead zone.** Below 0.08 the offset is treated as exactly zero, so sensor jitter
does not keep nudging the wheels.

## Obstacle Strategy

Red on the right, green on the left.

### One calculation instead of nine cases

The obvious implementation is a case per situation: red left, red centre, red right, the
same three for green, plus no sign. Nine branches, nine opportunities for a mistake.

Instead each colour is given a **target position in the frame**:

```python
PASS_TARGET = {COLOUR_RED: -0.5, COLOUR_GREEN: +0.5}
steering = (offset - PASS_TARGET[colour]) * STEERING_GAIN
```

Passing a red sign on its right means the sign ends up on our left, so its target is
-0.5. We steer by however far it is from that target.

| Red sign at | Frame offset | Steering |
|---|---|---|
| Far left | -0.91 | 0, already clear |
| Just left of centre | -0.53 | 0, just cleared |
| Centred | 0.00 | +15 degrees |
| Right of centre | +0.30 | +24 degrees |
| Far right | +0.56 | +30 degrees, full lock |

A centred sign produces the strongest correction and a sign far to one side produces
none. That is correct, and it emerges from the model rather than being written as a rule.

### The clamp that prevents clipping

```python
steering = max(0.0, steering) if colour is RED else min(0.0, steering)
```

A red sign may only ever produce right steering. Without this, a sign already cleared to
the left produces a small correction back towards it, which is exactly how you clip one.

### Choosing between two signs

The nearer sign is the one about to be hit, so that is the one acted on. The far one is
handled on later frames, once it becomes the near one. Distance is used when vision has
measured it; apparent size is the fallback, since a nearer sign of the same real size
looks bigger.

### The four phase pass

`FOLLOW_COURSE` then `APPROACH_PILLAR` then `PASS_PILLAR` then `RECENTER`.

**Recentring is the phase that was missing at first.** The early version steered around a
sign and carried on. Each obstacle left the robot slightly further from the lane centre,
and three signs later it clipped a wall. Now, once the sign has been out of view for
half a second, steering ignores signs entirely and tracks the lane centre until the
offset is back inside the dead zone.

**`PASS_PILLAR` has no route to recovery**, deliberately. Losing sight of a sign you are
squeezing past is what success looks like, so both exits lead to recentring.

## Algorithm Justification

### Why proportional control and not PID

We can implement PID. We chose not to.

A PID controller has three constants that interact: changing one changes what the
correct value of the others would be. Tuning it properly requires repeated tests in the
conditions it will run in.

At a competition you get limited practice time, on an unfamiliar table, under lighting
you did not choose, with two attempts that count. Our steering has **one gain and one
rate limit**. If the robot swings wide, we know which number to change and in which
direction, and any team member can do it.

The derivative term is also the one that would help most, and it is the one most damaged
by noisy sensor readings at 30 frames per second.

**Determinism and tunability beat theoretical optimality when the tuning happens under
pressure.**

### Why HSV and not RGB for colour detection

In RGB, brightness contaminates every channel. A red sign in shadow has a lower red
value than a white wall in sunlight.

HSV separates hue from brightness, so "red" becomes a hue range and the brightness
variation lives in a separate number we can be permissive about.

### Why a fill ratio test on contours

Taking the largest contour locks onto a red jacket in the audience or a stripe of glare
on the mat.

A real sign fills most of its bounding box. Scattered reflections may have a large total
area but are spread out. Requiring area **and** aspect ratio **and** fill ratio rejects
both false positives, and the self test proves it by placing a wide red stripe with the
largest area in the frame and checking the detector skips it.

### Why apparent height for distance

A sign is a known 10 cm tall, so the ratio of real height to pixel height gives range
from a single camera, with no stereo rig and no additional sensor.

The focal length cancels in the clearance calculation, which means the steering geometry
needs no camera calibration at all. Only the reported distance number does.

### Why quaternions from the IMU

The BNO085 reports orientation as a quaternion. We convert to Euler angles for
readability, but the chip works in quaternions because they avoid gimbal lock, a
degenerate case where two rotation axes align and one degree of freedom is lost.

Irrelevant for a ground robot, but it is why the conversion includes a clamp: floating
point rounding can push the `asin` argument fractionally past 1.0 and raise an error.

### Why hysteresis on every threshold

A single threshold with a noisy reading flips state on alternate frames. Readings of
399, 401, 398, 402 against a 400 mm threshold changed the speed mode four times in four
frames, and the robot audibly surged.

Separate enter and exit thresholds mean a reading near the boundary cannot cause a
change.

### Why a steering rate limit

One bad detection can only move the wheels 6 degrees rather than slamming them to full
lock. Full lock takes five frames, about 170 ms at 30 fps, which is fast enough to react
and slow enough that noise does not reach the servo.

## Edge Cases

| Case | Handling | Where |
|---|---|---|
| Sign flickers out for one frame | Half a second of confirmation before the pass ends | state machine |
| Two signs visible at once | Nearest wins; list order is irrelevant | navigation |
| Sign appears during a corner | Corner outranks sign, by table row order | state machine |
| Blob below minimum area | Treated as noise | vision |
| Sign jitters at frame centre | Dead zone snaps offset to zero | navigation |
| Distance sensor returns nothing | Speed drops to slow rather than cruising blind | navigation |
| Both side sensors fail mid corner | Hold the turn already in progress | navigation |
| Nothing detected at all | Fall back to lane following | navigation |
| Red jacket in the audience | Fill ratio test rejects it | vision |
| Magenta parking marker | Separate hue band; red narrowed to avoid overlap | vision |
| Only one parking marker visible | Not treated as a slot; keep searching | state machine |
| Robot wedged against a wall | Encoder stall detection triggers recovery | state machine |
| Corner never completes | Timeout to recovery, floor prevents the freeze | state machine |
| Pi crashes or cable drops | Watchdog stops the robot after 500 ms | Pico |
| Camera frame drops | Skip it, try again | Pi main |
| Corrupt byte on the serial link | Decoded with errors ignored | Pi main |
| Missing sensor driver file | That sensor reports itself; others keep working | Pico sensors |

## Testing and Tuning

### The testing workflow

**Level 1, module self tests.** Every module carries a `selftest()` that runs on a
laptop with no hardware. Fifteen of the sixteen modules are covered. They run in
milliseconds, so they run constantly during development.

```
python3 navigation_engine.py --selftest
python3 state_machine.py --selftest
```

**Level 2, structural assertions.** The tests we value most check the shape of the code
rather than a value, because they catch a half finished edit:

```python
assert set(TRANSITIONS) == set(State)          # every state has a transition row
assert PARKING_STOP_MM < STOP_ENTER_MM         # the parking trigger is reachable
assert set(MISSION_STATES) == set(Mission)     # every mission is described
```

**Level 3, cross board contract test.** The Pico's self test loads the **Pi's actual
parser**, not a copy, and checks a state line round trips through it. That is how we know
both boards agree on the message format.

**Level 4, bench testing.** One subsystem at a time, wheels off the ground, in the order
recorded in [the test log](../other/engineering-journal/test-logs.md).

**Level 5, field testing.** Full runs on a mat.

### The tuning process

<!-- TODO: record actual tuned values and what they were before. -->

| Constant | What it changes | How to tune |
|---|---|---|
| `STEERING_GAIN` | How hard the robot corrects for a sign | Raise if it clips signs, lower if it swerves wide |
| `STEERING_MAX_CHANGE_DEG` | How fast the wheels can move | Lower is smoother, higher reacts faster |
| `LANE_GAIN` | How hard it corrects lane drift | Raise if it wanders, lower if it weaves |
| `PASS_TARGET_OFFSET` | How wide a berth signs get | Raise for more clearance |
| `CORNER_TRIGGER_MM` | When a corner begins | Raise to turn earlier |
| `CRUISE_SPEED` | Straight line speed | Raise until the robot stops finishing reliably, then back off |

**Change one at a time.** Two changes at once and you cannot attribute the difference.

## Metrics

Numbers we use to judge whether a change helped.

### Measured

| Metric | Value | How |
|---|---|---|
| Vision pipeline cost | **0.32 ms per frame** | Timed over 300 frames on a development laptop |
| Modules with self tests | **15 of 16** | The sixteenth is a shell script |
| State machine size | 12 states, 17 events, 30 transitions | |
| Sensor sweep cost | ~132 ms | Four ToF at 33 ms each |
| Pico command latency | under 20 ms | Loop period |

The vision figure is the one that mattered most: at 0.32 ms per frame, the camera's
frame rate limits the robot rather than the processing. That is the right way round, and
it is why we downscale to 320 pixels rather than optimising further.

### To be measured

<!-- TODO: these are the metrics that will validate performance on the mat.
     The rubric asks specifically for "metrics used to validate performance". -->

| Metric | Target | Measured |
|---|---|---|
| Laps completed out of attempts | | |
| Signs passed correctly out of signs encountered | | |
| Corners completed without recovery | | |
| Parking success rate | | |
| Time for three laps, Open | | |
| Time for three laps, Obstacle | | |
| Frames per second on the Pi 3 | | |
| Recovery events per run | | |

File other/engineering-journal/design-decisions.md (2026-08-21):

# Design Decisions

Why the robot is built the way it is.

## Constraints We Designed Around

Every one of these came from either the rulebook or the hardware, and each forced a
decision we would not otherwise have made.

| Constraint | Source | What it forced |
|---|---|---|
| Parking slot is 1.5 times the robot's length | Rule | Chassis kept to 15 cm. Every centimetre of car costs 1.5 cm of slot, so a longer robot parks in a proportionally longer space and gains nothing. |
| Drive wheels must be physically connected | Rules 11.3 and 11.5 | One motor through a gearbox rather than one motor per side. |
| One button to power on, one to start | Rules 9.10 and 9.11 | No laptop interaction at the start line. |
| Track layout randomised every round | Rule | Nothing hard coded. No memorised turn sequence, no fixed timings, all behaviour driven by what the sensors report. |
| Distance and colour sensors share I2C address 0x29 | Hardware | A multiplexer is unavoidable. |
| RP2350 is not 5 V tolerant | Hardware | Every sensor output has to be on the 3.3 V rail. |
| Linux is not a real time operating system | Platform | Control split across two boards. |

## Key Trade-offs

| Decision | What we chose | What we rejected | Reasoning |
|---|---|---|---|
| Compute | Pi 3 and Pico together | A single Pi doing everything | A non real time operating system can stall a control loop for tens of milliseconds. That is invisible when processing an image and disastrous when a servo is waiting for a pulse. |
| Sensor addressing | TCA9548A multiplexer | Reassigning addresses via the shutdown pins at boot | Address reassignment needs a boot sequence that can fail silently, and one extra GPIO per sensor. |
| Side sensor angle | 45 degrees | 90 degrees, straight out to the sides | At 90 degrees a corner only appears once you are level with it, which is too late to plan a turn. At 45 degrees the same sensors watch the forward diagonals. |
| Steering control law | Proportional, one gain | PID | A PID controller has three interacting constants. A competition venue is the worst possible place to tune three interacting constants under time pressure. |
| Which sign to act on | The nearest one | The largest contour in the frame | Largest is only correct by accident. When two signs are visible, the near one is the one about to be hit. |
| Detection resolution | 320 pixels wide | Full camera resolution | Roughly five times fewer pixels. The camera frame rate becomes the limit rather than the processing, which is the right way round. |
| Parking entry | Nose first | Reversing in | The camera faces forward, so the slot is only visible while driving towards it. Reversing in means backing in blind. |

## Why We Did Not Use PID

We can implement a PID controller. We chose not to, and it is worth explaining because
it looks like a gap.

A PID controller has three constants that interact with each other. Changing one
changes what the correct value of the other two would be. Tuning it properly needs
repeated tests in the conditions it will run in.

At a competition you get limited practice time on an unfamiliar table, under lighting
you did not choose, with two attempts that count. Our steering has **one gain and one
rate limit**. If the robot swings too wide we know which number to change and in which
direction, and any of the three of us can do it.

Determinism and tunability beat theoretical optimality when the tuning has to happen
under pressure.

## Risk Analysis

What could go wrong, how bad it would be, and what we did about it.

| Risk | Impact if unmitigated | Mitigation |
|---|---|---|
| Pi crashes mid run | Robot keeps driving on its last command until it hits something | The Pico stops the robot if no command arrives for 500 ms. This is the single most important reason the control system is split across two boards. |
| Serial cable comes loose | Same as above | Same watchdog. The Pi also keeps retrying the connection rather than exiting. |
| One sensor fails | A crash in the reading code takes down every other sensor with it | Every sensor returns nothing rather than raising. One dead sensor costs one reading. |
| A driver file is missing from the board | All six sensors silently dead | Driver imports are isolated from each other and from the I2C setup. Each reports itself by name at startup. |
| Voltage sag when the servo hits full lock | The Pi browns out and reboots mid run | Decoupling capacitor at the motor driver, and a power budget sized on peak rather than average draw. |
| Robot wedges against a wall | The round is over and nothing notices | Encoder detects that the robot is commanded to move but is not moving, and triggers recovery. |
| A corner never completes | The robot freezes facing a wall | The state times out into recovery, and a minimum speed prevents the freeze in the first place. |
| Serial clock drift on the Pi 3 | Corrupted bytes, but only under processor load | Bluetooth disabled so the port uses the stable hardware UART. |
| A sign is detected on the wrong side | Robot steers into the thing it is meant to avoid | The pass direction is clamped per colour, so a red sign can only ever produce right steering. |

### The Fault We Caught Before It Cost Us a Board

Our first connection list put the N20 encoder on the 5 V rail.

A magnetic encoder outputs at whatever voltage supplies it. On 5 V, its two channels
would have driven 5 V straight into GP12 and GP13, and the RP2350 has an absolute
maximum of 3.3 V plus 0.3 V on any GPIO pin.

The reason this one is worth recording is the failure mode. It would have worked on the
bench. The board would have died days or weeks later, and it would have looked exactly
like a software bug, because the symptom would have been sensor readings quietly going
wrong rather than anything obviously electrical.

The encoder now runs from the Pico's 3.3 V rail, where it draws a few milliamps. The
lesson we took from it was to trace the logic level path of every sensor output, not
just check that its supply voltage is correct.

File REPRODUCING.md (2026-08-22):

# Reproducing This Robot

Everything another team needs to build and run this robot from scratch.

Covers rubric criterion 5. If a step here is unclear, that is a bug in this document.

## Contents

1. [What you need](#what-you-need)
2. [Build the mechanics](#build-the-mechanics)
3. [Wire the electronics](#wire-the-electronics)
4. [Set up the Raspberry Pi](#set-up-the-raspberry-pi)
5. [Set up the Pico](#set-up-the-pico)
6. [Calibrate](#calibrate)
7. [Testing workflow](#testing-workflow)
8. [Version history](#version-history)

## What you need

### Electronics

| Part | Quantity | Notes |
|---|---|---|
| Raspberry Pi 3 Model B | 1 | With a micro SD card, 16 GB or more |
| Raspberry Pi Pico 2 W | 1 | The RP2350 board, not the older RP2040 Pico W |
| Camera Module 3 | 1 | Plus a **15 pin** ribbon cable for the Pi 3 |
| GA12-N20 gear motor with encoder | 1 | 6 V. Record the gear ratio you buy. |
| MG90S servo | 1 | Metal geared |
| DRV8833 motor driver | 1 | |
| VL53L0X distance sensor | 4 | |
| TCA9548A I2C multiplexer | 1 | |
| BNO085 IMU | 1 | |
| TCS34725 colour sensor | 1 | |
| Mini560 buck converter | 1 | 5 V output |
| 2S LiPo battery | 1 | 7.4 V, 1500 mAh, 35C |
| 4.7 kohm resistors | 2 | I2C pull-ups |
| 100 uF electrolytic capacitor | 1 | Across the motor driver supply |
| 0.1 uF ceramic capacitor | 1 | Across the motor terminals |

Full parts list with sourcing in
[`schemes/Main Electrical Components.xlsx`](schemes/Main%20Electrical%20Components.xlsx).

### Printed parts

All in [`models/`](models/), one folder per part with the CAD file and a render.

<!-- TODO: record your print settings so another team can match them.
| Setting | Value |
|---|---|
| Material | |
| Layer height | |
| Infill | |
| Supports | |
-->

### Tools and software

A 3D printer, a soldering iron, and calipers. On your computer: Python 3 with OpenCV and
pyserial, and `mpremote` for the Pico.

## Build the mechanics

1. Print the four body sections, the camera mount and the battery mount from
   [`models/body/`](models/body/).
2. Print or machine the steering assembly from
   [`models/front-steering/`](models/front-steering/) and the motor mount from
   [`models/rear-drive/`](models/rear-drive/).
3. Assemble the Ackermann linkage. Check both front wheels rotate freely and that the
   inside wheel turns through a larger angle than the outside one when steered.
4. Fit the motor and rear axle. Check for play between the motor shaft and the wheels,
   since any flex here becomes odometry error.
5. Mount the camera and, directly beneath it on the underside, the colour sensor.

Reasoning behind each part is in
[`models/mechanical-design.md`](models/mechanical-design.md).

## Wire the electronics

Follow the master connection list in [`schemes/README.md`](schemes/README.md) exactly.
The sensor layout is drawn in
[`schemes/sensor-placement.svg`](schemes/sensor-placement.svg).

**Three things that will cost you a board or a day if you get them wrong.**

Every sensor output must be on the **3.3 V** rail. The RP2350 is not 5 V tolerant, and a
sensor supplied at 5 V outputs 5 V logic. This kills the board days later and looks like
a software bug.

The DRV8833's **nSLEEP** pin must be high. Otherwise the motor does nothing while every
print statement reads correct.

**Grounds must be common.** The battery ground, the 5 V ground and the logic ground are
one net.

Full reasoning in [`schemes/power-and-sensors.md`](schemes/power-and-sensors.md).

## Set up the Raspberry Pi

```bash
sudo apt install python3-opencv python3-pip
pip install pyserial
```

Then move the serial port off the mini UART, which is a **Pi 3 specific** step:

```bash
sudo nano /boot/firmware/config.txt     # add: enable_uart=1
                                        #      dtoverlay=disable-bt
sudo systemctl disable hciuart
sudo raspi-config                       # Serial: login shell NO, hardware YES
sudo reboot
ls -l /dev/serial0                      # must point at ttyAMA0, not ttyS0
```

Skipping this gives a link that works at idle and corrupts bytes the moment the vision
code loads the processor.

## Set up the Pico

Flash MicroPython, using the **RP2350** build for the Pico 2 W. Hold BOOTSEL, plug in
USB, drag the `.uf2` file onto the drive that appears.

Then fetch the three sensor drivers into `src/pico/drivers/`:

<!-- TODO: record the exact driver sources you used, so another team gets the same
     versions. The modules import them as vl53l0x, tcs34725 and bno08x. -->

| Driver | Import name | Source |
|---|---|---|
| VL53L0X | `vl53l0x` | *record the URL and version* |
| TCS34725 | `tcs34725` | *record the URL and version* |
| BNO08x | `bno08x` | *record the URL and version* |

Then deploy:

```bash
cd src/pico
./deploy.sh --drivers
```

Everything lands flat at the board's root, because MicroPython's `import distance` does
not know about folders.

## Calibrate

Every one of these is specific to your build. Full method for each in
[`schemes/power-and-sensors.md`](schemes/power-and-sensors.md).

| Constant | File | Measure by |
|---|---|---|
| `GEAR_RATIO` | `encoder.py` | Turn the wheel ten revolutions, divide the pulse change by ten |
| `WHEEL_DIAMETER_MM` | `encoder.py` | Calipers, with the robot's weight on the wheel |
| `CENTRE_US` | `servo.py` | Adjust until the wheels are dead straight |
| `MAX_STEER` | `servo.py` | Reduce until the servo no longer strains at full lock |
| `CAMERA_HFOV_DEG` | `vision_test.py` | Sign at a measured 50 cm, adjust until the readout agrees |
| `ROI_TOP` | `vision_test.py` | Set once the camera is mounted |
| `COLOUR_RANGES` | `vision_test.py` | Mask view, on the real mat, under competition lighting |
| `MAGENTA_RANGE` | `vision_test.py` | Same, on the real parking markers |

Two direction flags are set by observation, not by rewiring. `STEER_DIRECTION` if the
servo turns the wrong way, `ENCODER_DIRECTION` if forward counts down. If the motor spins
backwards, swap the two motor wires.

## Testing workflow

Work up the levels. Do not skip.

### Level 1: self tests, no hardware

Every module carries one. They run on a laptop in milliseconds.

```bash
cd src/pi3
python3 camera_vision/vision_test.py --selftest
python3 navigation_engine.py --selftest
python3 state_machine.py --selftest
python3 mission_manager.py --selftest
python3 main.py --selftest

cd ../pico/sensors
PYTHONPATH=.. python3 -c "
import distance, imu, colour, sensorManager, servo, drv8833, encoder, motionController
for m in (distance, imu, colour, sensorManager, servo, drv8833, encoder, motionController):
    m.selftest()"
```

All fifteen should print `selftest ok`. **Run these after every change.**

### Level 2: vision on a laptop

```bash
python3 main.py --dry-run --show
```

Webcam and full decision logic, no robot. Hold coloured objects in front of the camera
and watch the detections and the chosen behaviour.

### Level 3: bench, wheels off the ground

One subsystem at a time, in this order. Set `MAX_SPEED = 40` first.

1. Servo centres straight, reaches both limits without straining
2. Motor spins the correct way, and **stops from every speed**
3. Encoder counts one turn correctly, counts down in reverse
4. All four distance sensors respond, and the right one changes when you block it
5. IMU heading changes correctly when the robot is turned
6. Colour sensor distinguishes the real mat surfaces
7. Serial link survives five minutes with the vision code loading the Pi

Record results in
[`other/engineering-journal/test-logs.md`](other/engineering-journal/test-logs.md).

### Level 4: field

Full runs on a mat. Log every attempt, including the failures, especially the failures.

## Version history

<!-- TODO: tag releases as milestones are reached, and record them here. The rubric
     asks for "versioning or release notes". A tag before each competition round is
     the minimum worth doing. -->

| Version | Date | What changed |
|---|---|---|
| | | |

To tag a version:

```bash
git tag -a v1.0 -m "First complete software stack, all self tests passing"
git push --tags
```

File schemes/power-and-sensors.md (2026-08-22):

# Power and Sensor Architecture

Power budget, current draw reasoning, sensor selection and placement, calibration
method, and failure point analysis.

Covers rubric criterion 2. Wiring diagrams and the full connection list are in
[README.md](README.md) and the schematic files alongside it.

## Contents

1. [Power Architecture](#power-architecture)
2. [Current Draw Reasoning](#current-draw-reasoning)
3. [Sensor Selection](#sensor-selection)
4. [Sensor Placement](#sensor-placement)
5. [Calibration Method](#calibration-method)
6. [Failure Points](#failure-points)
7. [Iterations](#iterations)

## Power Architecture

```
Battery 7.4 V 2S LiPo
   |
   +---------------------------> DRV8833 VM (motor supply, unregulated)
   |
   +--> Mini560 buck --> 5 V rail --> Raspberry Pi 3
                                  --> Pico 2 W (VSYS)
                                  --> MG90S servo
                                        |
                          Pico 3V3 OUT --+--> TCA9548A multiplexer
                                         +--> 4x VL53L0X
                                         +--> BNO085 IMU
                                         +--> TCS34725 colour
                                         +--> N20 encoder
                                         +--> DRV8833 nSLEEP
```

### The one deliberate choice in this diagram

The motor supply taps the **raw battery**, in parallel with the buck converter's input,
rather than running off the regulated 5 V rail.

**What we gain.** Motor current never passes through the regulated logic rail. A motor
draws its largest current exactly when it is working hardest, and those spikes would
otherwise sag the voltage feeding the Pi, the Pico and every sensor. The Pi reboots if
its supply dips, and a reboot mid run ends the round.

**What it costs.** The battery sits above the motor's 6 V rating when freshly charged,
so running at 100 percent duty would overdrive it. This is why the PWM duty is limited
in software rather than left uncapped, and why `MAX_SPEED` exists as a constant rather
than being assumed to be 100.

**The alternative we rejected.** Running the motor from the regulated 5 V would have
protected the motor automatically, at the cost of putting every current spike through
the same regulator that feeds the Pi. We would rather software-limit the motor than
risk the brain rebooting.

### Three voltage domains

| Domain | Voltage | What runs on it | Why |
|---|---|---|---|
| Battery | 7.4 V nominal | Motor only | Isolates current spikes from everything else |
| Logic supply | 5 V regulated | Pi, Pico, servo | What these boards expect |
| Sensor logic | 3.3 V | Every sensor, the multiplexer, nSLEEP | The RP2350 is not 5 V tolerant |

**That last row is a hard rule, not a preference.** Any GPIO on the RP2350 has an
absolute maximum of 3.3 V plus 0.3 V. Every sensor output has to be inside that.

## Current Draw Reasoning

| Consumer | Typical | Peak | When the peak happens |
|---|---|---|---|
| Raspberry Pi 3 | ~700 mA | ~2.5 A | Vision processing on all four cores |
| MG90S servo | ~200 mA | ~1.5 A | Stall, or slamming to full lock |
| GA12-N20 motor | ~150 mA | ~800 mA | Stall, or accelerating from rest |
| Pico 2 W and six sensors | ~150 mA | ~200 mA | Continuous |
| **Total** | **~1.2 A** | **~5 A** | |

### Why the peak is the number that matters

The typical figure tells you battery life. The peak figure tells you whether the robot
works at all.

The three peaks are not independent. The servo hits full lock when the robot is
cornering or dodging a sign, which is exactly when the vision workload is highest and
the motor is working against a turn. They coincide, and they coincide at the worst
possible moment.

If the 5 V rail sags below the Pi's tolerance during that moment, the Pi reboots. The
Pico's watchdog then stops the robot after 500 ms, which is the correct behaviour but
still ends the run.

### Mitigations

| Measure | What it addresses |
|---|---|
| Motor on the unregulated rail | Removes the largest current spike from the regulated supply entirely |
| 100 uF electrolytic across the driver's VM and GND, at the driver | Supplies the instantaneous current a motor demands at switch-on, so it is not drawn through the wiring |
| 0.1 uF ceramic across the motor terminals | Suppresses brush noise, which otherwise couples into the encoder lines |
| Software speed limit | Keeps the motor away from stall current in normal operation |
| Ground plane on the PCB | Low impedance return path, so ground does not shift under load |

<!-- TODO: measure these. A power budget with measured numbers scores far better
     than one with estimates.
| Measurement | Value |
|---|---|
| Idle current, whole robot | |
| Current while driving straight | |
| Peak current, servo to full lock while accelerating | |
| 5 V rail voltage under that peak | |
| Battery run time, continuous driving | |
-->

## Sensor Selection

Each sensor exists because something else could not do its job.

### Camera Module 3

**Chosen because it is the only sensor that distinguishes colour.** The entire obstacle
challenge depends on telling red from green, and no distance sensor can do that.

It is also the only sensor with useful range for planning. A ToF sensor tells you
something is 400 mm away; the camera tells you it is a red sign 400 mm away and slightly
to the left, which is enough to plan a path rather than react.

**Rejected alternative:** a colour sensor pointed forward. Far cheaper, but it gives a
single reading with no idea where in the field of view the colour is.

### VL53L0X, four of them

**Chosen over ultrasonic.** Ultrasonic sensors are cheap and have good range, but they
have a wide beam, they are confused by soft or angled surfaces, and multiple units
interfere with each other. Four of them firing near each other would cross-talk badly.

The VL53L0X uses a narrow infrared laser and time of flight. Narrow beam means it
measures what it is pointed at rather than averaging a cone.

**Why four and not one.** One forward sensor tells you something is ahead. Four tell you
where you are in the lane, whether a corner is coming, and whether there is room behind
you to park. Position is a different question from proximity.

**Rejected alternative:** LIDAR. Better data, but larger, more expensive, and needs more
processing than a Pico can give it.

### BNO085 IMU

**Chosen because heading cannot be derived from anything else we have.** Wheel odometry
drifts as soon as a wheel slips, and it slips most during exactly the turns you most
want to measure.

**Chosen over a cheaper IMU** such as an MPU6050, because the BNO085 runs sensor fusion
on its own processor. A raw accelerometer and gyroscope would need a filter written and
tuned by us, running on the Pico, competing with everything else for time.

### TCS34725 colour sensor

**Chosen for redundancy and for the corner lines.** The mat marks corners with coloured
lines, and reading them directly under the robot is more reliable than trying to see
them at an angle in the camera.

**Its infrared filter is the reason we can use it at all.** Four infrared distance
sensors are firing a few centimetres away. A colour sensor without an IR filter would
read their light as a large fake contribution to every channel.

### TCA9548A multiplexer

**Chosen because it is unavoidable.** Every VL53L0X has fixed I2C address 0x29, and so
does the TCS34725. Two on a bus and both answer at once.

**Rejected alternative:** using the XSHUT pins to bring each sensor up one at a time and
reassign addresses at boot. That needs one GPIO per sensor and a boot sequence that can
fail silently, leaving two sensors on the same address with no error.

The multiplexer costs sequential reads instead of parallel ones, which is a real cost:
a full sweep of four ToF sensors takes about 132 ms. We handle that by running the
sensor sweep on a slower schedule than the control loop.

## Sensor Placement



### Placement justified by field geometry

**The two 45 degree sensors are the placement decision we spent longest on.**

The field is a rectangular track with walls on both sides. What the robot needs to know
is where it sits across the lane, and when a corner is arriving.

A sensor at 90 degrees, pointing straight out to the side, measures lane position well.
But it only sees a corner once the robot is already level with it, which is far too late
to plan a turn at speed.

A sensor at 0 degrees sees the corner early but says nothing about lateral position.

At 45 degrees, one sensor does both. It watches the forward diagonal, so an approaching
inner wall appears while there is still room to react, and the comparison between the
left and right diagonals still gives lane position.

**The cost, written at the top of the distance module.** A reading of D millimetres at
45 degrees is **not** lateral clearance. It is roughly 0.71 times D ahead and 0.71 times
D to the side. Code that treats it as lateral clearance drives the robot into a wall.

### Lane position without knowing the lane width

```
offset = (right - left) / (right + left)
```

Dividing by the total is what makes this work regardless of lane width. Being one third
of the way across a 1 metre lane and one third across a 2 metre lane give the same
answer, so the robot does not need to be told the track dimensions.

### The colour sensor position

Mounted on the underside of the nose, below the camera mount, rather than under the
middle of the chassis.

**Field geometry reason.** Corner lines run across the track. A sensor at the front
crosses the line before the wheels do, which converts into reaction time at exactly the
moment it is needed. Under the middle of the car, the robot is already on the line when
it finds out.

### The IMU position

Set back behind the drive assembly.

**Why this is allowed to be a packaging decision.** Yaw is a property of the whole rigid
body, not of a point on it. The heading reading is identical wherever the sensor is
bolted, so the IMU can go wherever there is flat, rigid space. That freed the crowded
nose for the sensors whose position genuinely matters.

## Calibration Method

Each of these has to be measured on this specific robot. The software cannot derive
them.

### Camera field of view

**Why.** Distance to a sign is computed from its apparent height, and the conversion
depends on the camera's field of view.

**Method.** Place a sign at a measured 50 cm directly ahead. Run the vision module and
read the reported distance. Adjust `CAMERA_HFOV_DEG` until the readout matches. Verify
at 30 cm and 100 cm, since a single point can be matched by a wrong value.

### Colour thresholds

**Why.** The HSV ranges decide whether a sign is seen at all, and they depend on the
lighting in the room.

**Method.** Run the vision module and press **M** for the mask view. Point the camera at
each real object on the real mat. The object should appear solid white in the mask, with
nothing else white. Widen the range until it does, then narrow it until other things
stop appearing.

**Do this under competition lighting, not bench lighting.** This is the calibration most
likely to fail if done in the wrong room.

### Servo centre

**Why.** No two steering linkages sit neutral at the same pulse width.

**Method.** Send a command of zero steering. Look along the car. Adjust `CENTRE_US` until
the wheels are dead straight. Roughly 10 microseconds per degree of error.

### Maximum steering angle

**Why.** The software limit must be the mechanical limit, not the servo's limit.

**Method.** Command full lock in each direction. If the servo buzzes, strains or gets
warm, the linkage is hitting a stop before the servo reaches the commanded angle. Reduce
`MAX_STEER` until it is silent.

### Wheel diameter and gear ratio

**Why.** These two numbers scale every distance the robot calculates.

**Method for the ratio.** Mark the tyre, turn the wheel exactly ten full revolutions by
hand, and divide the pulse count change by ten. Ten turns rather than one so that eye
error on the mark is divided by ten too.

**Method for the diameter.** Measure across the tyre **with the robot's weight on it**,
since rubber compresses. Then roll the robot along a metre stick and compare against the
reported distance, adjusting until they agree.

### Colour sensor gain and integration time

**Why.** Set too high, the clear channel saturates and everything bright reads as white.

**Method.** Point at the brightest surface the robot will see. The clear value should
land well below its maximum. Reduce gain or integration time until it does. This is the
single most common cause of a colour sensor that "always says white".

<!-- TODO: record the measured values here once calibrated, so another team can
     reproduce the robot without repeating the whole process.
| Constant | Measured value | Date |
|---|---|---|
-->

## Failure Points

What can fail electrically, what it would look like, and what we did about it.

| Failure | Symptom | Mitigation |
|---|---|---|
| 5 V rail sags at peak load | Pi reboots mid run, which looks like a software crash | Motor on the unregulated rail, decoupling at the driver, peak-based power budget |
| Sensor supplied at 5 V drives a 3.3 V pin | Works on the bench, microcontroller dies days later | Every sensor output on the 3.3 V rail. See below. |
| One I2C device holds the bus | All six sensors stop responding | Every read is wrapped, and a failed sensor returns nothing rather than raising |
| A driver file missing from the board | All sensors dead with no obvious cause | Driver imports isolated from each other; each reports itself by name |
| Motor brush noise couples into encoder lines | Phantom counts under power, clean by hand | Capacitor across the motor terminals, encoder wiring routed away from motor leads |
| Serial clock drift on the Pi 3 | Corrupted bytes, but only under processor load | Bluetooth disabled to force the stable hardware UART |
| Loose connector | Intermittent sensor dropout | Sensor readings that go missing degrade the robot rather than stopping it |
| Battery sags as it discharges | Robot slows over a session, colour thresholds drift | Monitor run time, recalibrate colour after a voltage change |

### The 5 V fault we caught in review

Our first connection list put the N20 encoder on the 5 V rail.

A magnetic encoder outputs at whatever voltage supplies it. On 5 V, its two channels
would have driven 5 V straight into GP12 and GP13, against an absolute maximum of
3.3 V plus 0.3 V.

**Why this one is worth recording.** It would have worked. The board would have died
days or weeks later, and the symptom would have been sensors quietly reading wrong,
which looks exactly like a software bug. We would have spent that time debugging code.

The encoder now runs from the 3.3 V rail, where it draws a few milliamps.

**The rule we took from it:** trace the logic level path of every sensor output, not just
check that its supply voltage is correct.

### The nSLEEP trap

The DRV8833 has an nSLEEP pin that must be high or the driver stays asleep. It was
missing from our first connection list entirely.

The failure mode is that the motor does nothing while every print statement in the code
reads perfectly correct. It is tied to 3.3 V now.

## Iterations

<!-- TODO: record electrical changes here as they happen. -->

| Change | Reason | Result |
|---|---|---|
| Encoder moved from 5 V to 3.3 V | Would have destroyed the microcontroller | Caught before any hardware was damaged |
| nSLEEP added to the connection list | Driver would never have woken up | |
| Decoupling capacitor added at the driver | Peak current budget showed the rail could sag | |
| Red hue band narrowed from 165 to 172 | Magenta parking markers were read as red signs | Both colours now detected in the same frame |
| Saturation and value floors lowered | The dimmer of two signs was silently dropped | Both signs detected regardless of lighting |

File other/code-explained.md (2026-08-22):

# Tricky Trio Code Explained

A line by line walkthrough of every file in the robot, written for someone who has not
seen the code before.

## How to read this document

The robot has two computers, so this document has two halves.

**PI** is the Raspberry Pi 3. It has a camera, runs Linux, and does the thinking. It
answers questions like "is there a red sign ahead" and "how hard should I turn".

**PICO** is the Raspberry Pi Pico 2 W. It is a microcontroller, which means it has no
operating system and does exactly one thing at a time, very reliably. It answers
questions like "put the servo at 20 degrees" and "how many times has the wheel turned".

They talk to each other over three wires.

## The one idea that explains the whole design

Linux can pause. If the Pi decides to save a file, or the Wi-Fi chip interrupts it, your
program stops for a few milliseconds and then carries on. You never notice this when
you are browsing the internet.

A servo notices. A servo needs a pulse every 20 milliseconds, forever. Miss one and it
twitches.

So the rule is: **anything with a deadline runs on the Pico, anything that needs to
think runs on the Pi.** Almost every design decision in this code follows from that one
sentence.

## Vocabulary you will need

**Module.** One file of Python code. `servo.py` is a module.

**Function.** A named block of code you can run. `def move(speed, steering):` defines a
function called `move` that takes two pieces of information.

**Argument.** The information you hand a function. In `move(45, 20)`, the arguments are
45 and 20.

**Return.** What a function hands back when it finishes.

**Constant.** A value with a name, written in CAPITALS, that does not change while the
program runs. `MAX_STEERING_DEG = 30`.

**Dictionary.** A lookup table. `{"speed": 45, "steering": 20}` lets you ask for
`command["speed"]` and get 45.

**Tuple.** A list that cannot be changed after it is made, written with round brackets.

**PWM.** Pulse Width Modulation. A way of getting an on/off pin to act like a dial, by
switching it on and off very fast and varying how long it stays on.

**I2C.** A way for several chips to share two wires. Each chip has an address so they
know who is being spoken to.

**Self test.** A function inside a file that checks the file works. Every module here
has one, and they all run on a laptop with no robot attached.

# PI

Everything in this half runs on the Raspberry Pi 3, in normal Python 3.

Read the files in this order. Each one builds on the last.

## PI / mission_manager.py

**Job: say which of the three competition rounds we are running.**

This is the smallest file in the project, 44 lines, and it is a good place to start
because it shows the shape every other file follows.

```python
class Mission(Enum):
    OPEN_CHALLENGE = "OPEN_CHALLENGE"
    OBSTACLE_CHALLENGE = "OBSTACLE_CHALLENGE"
    PARKING = "PARKING"
```

An **Enum** is a fixed list of allowed values. Without it we would pass the text
`"OPEN_CHALLENGE"` around, and a typo like `"OPEN_CHALENGE"` would not be noticed until
the robot behaved strangely on the mat. With an Enum, `Mission.OPEN_CHALENGE` fails
instantly with an error, on the laptop, the moment you run it.

```python
MISSION = Mission.OBSTACLE_CHALLENGE
```

The one line you change before a run. It sits alone, in capitals, at the top, so nobody
has to hunt for it.

```python
def current_mission():
    return {"mission": MISSION.value, "reason": "Selected manually in config"}
```

Two things worth noticing.

`MISSION.value` gives the plain text `"OBSTACLE_CHALLENGE"` rather than the Enum object,
because the rest of the program works with text.

`"reason"` looks pointless right now, since the answer is always the same. It exists
because later this file will detect the mission automatically, and then the reason will
be something like "magenta markers visible, assuming parking". Everything that calls
this function already prints the reason, so when that day comes nothing else has to
change.

**Why this is a whole file for four lines of logic.** Because `main.py` asks it every
single frame rather than once at startup. That means swapping the constant for real
detection later touches only this file.

## PI / camera_vision/vision_test.py

**Job: look at a camera frame and say what is in it.**

330 lines. This is where the robot gets its eyes.

### The problem colour detection has to solve

A camera gives you red, green and blue values for every pixel. That sounds perfect for
finding a red sign, until you realise that a red sign in shadow has a *lower* red value
than a white wall in bright sun. Brightness contaminates everything.

**HSV** solves this. It describes a colour as three different numbers:

- **Hue**, what colour it is, as an angle from 0 to 179 in OpenCV
- **Saturation**, how strong the colour is, 0 to 255
- **Value**, how bright it is, 0 to 255

Now "red" is a hue range, and brightness lives in a separate number we can be relaxed
about. That is why the first thing the code does is convert.

### The colour ranges

```python
COLOUR_RANGES = {
    "RED": [((0, 90, 40), (10, 255, 255)), ((172, 90, 40), (180, 255, 255))],
    "GREEN": [((35, 70, 35), (90, 255, 255))],
}
```

Each entry is a lowest and highest HSV value. Anything between them counts.

**Red needs two ranges** because hue is a circle and red sits at the join. Hue 0 and hue
179 are both red, the way 23:59 and 00:01 are both nearly midnight. So we look for
0 to 10 and 172 to 180 and combine them.

**Why the saturation and value floors are so low.** Our first version used 110 and 70.
It worked perfectly with one sign and kept losing the second one. Two signs on a mat are
never lit equally, and the one further from the lights fell below the floor. It looked
random because it depended on where the robot was standing. Lowering the floors fixed it.

**Why red now starts at 172 and not 165.** Magenta, the parking marker colour, sits just
below red on the hue circle. With red starting at 165 the robot saw the parking lot as
one enormous traffic sign and tried to pass it on the right. Moving the start to 172
costs nothing, because red's main band is 0 to 10.

### Making a mask

```python
def colour_mask(hsv, ranges):
    mask = cv2.inRange(hsv, ...)
    for low, high in ranges[1:]:
        mask |= cv2.inRange(hsv, ...)
    mask = cv2.morphologyEx(mask, cv2.MORPH_OPEN, KERNEL)
    return cv2.morphologyEx(mask, cv2.MORPH_CLOSE, KERNEL)
```

`cv2.inRange` returns a **mask**: a black and white image where white means "this pixel
was inside the range". The `|=` merges red's two ranges into one mask.

The two morphology steps clean it up.

**Open** removes tiny white specks, the way you would brush dust off a photo. Camera
noise produces single stray pixels that pass the colour test.

**Close** fills small black holes inside white areas. A glossy sign has a bright
reflection on it that is not red, punching a hole in the middle of the shape.

Doing open first then close is deliberate: remove the dust before you fill the holes,
or you fill the dust in too.

### Finding the sign

```python
def find_block(mask):
    contours, _ = cv2.findContours(mask, cv2.RETR_EXTERNAL, cv2.CHAIN_APPROX_SIMPLE)
    best, best_area = None, MIN_AREA
    for contour in contours:
        area = cv2.contourArea(contour)
        if area <= best_area:
            continue
        x, y, w, h = cv2.boundingRect(contour)
        if not MIN_RATIO <= w / h <= MAX_RATIO:
            continue
        if area / (w * h) < MIN_FILL:
            continue
        best, best_area = (x, y, w, h), area
    return best
```

A **contour** is the outline of a connected white blob. This function picks the best one.

The obvious approach is "take the biggest blob". That is wrong, and it took us a while
to see why. The biggest red blob in the room might be a jacket in the audience, or a
long stripe of glare across the mat.

So a blob has to pass three tests:

**Area.** Bigger than `MIN_AREA`. Notice the trick: `best_area` starts at `MIN_AREA`, so
the single comparison `area <= best_area` does two jobs at once. It rejects blobs that
are too small *and* blobs that are worse than the best one found so far.

**Aspect ratio.** Width divided by height must be between 0.15 and 2.00. Signs are
taller than wide. A long horizontal stripe of glare has a ratio around 12 and fails.

**Fill ratio.** The contour's area divided by its bounding box area. A solid sign fills
most of its box, giving something above 0.8. Scattered reflections might have a large
total area but be spread out, giving 0.2. This is the test that rejects a person.

The self test deliberately puts a wide red stripe with the *largest area in the frame*
into a test image and checks the detector skips it in favour of the real sign.

**Why one pass and not sorting.** An earlier version sorted all contours by size and
walked the list. Sorting is unnecessary work when you only want the best one, and it
computed each area twice. This version does one pass and computes each area once.

### Working out how far away something is

```python
focal_px = (width / 2) / TAN_HALF_HFOV
distance = real_height_cm * focal_px / max(h, 1)
```

This is the whole reason we can get range from one camera with no second lens.

A sign is a known 10 cm tall. The further away it is, the fewer pixels tall it appears,
and the relationship is a simple division. Double the distance, half the pixel height.

`focal_px` converts between the two, and it depends on the camera's field of view, which
is why `CAMERA_HFOV_DEG` has to be calibrated for your camera.

`max(h, 1)` prevents dividing by zero if the height ever came out as 0.

`TAN_HALF_HFOV` is calculated once at the top of the file rather than every frame,
because it never changes.

### The region of interest

```python
roi_y = int(height * ROI_TOP)
small = cv2.resize(frame[roi_y:], (PROC_WIDTH, proc_height), ...)
```

Two speedups in two lines.

`frame[roi_y:]` throws away the top 35 percent of the image. Signs stand on the mat, so
the top of the frame contains only ceiling and lights. Ignoring it is free and removes a
whole category of false detection.

`cv2.resize` then shrinks what remains to 320 pixels wide. Detection does not need
detail; it needs to know roughly where a coloured rectangle is. Working at 320 instead
of 640 means roughly four times fewer pixels to examine.

Drawing still happens at full resolution, so what you see on screen is sharp.

The measured result is 0.32 milliseconds per frame, which means the camera's frame rate
limits the robot, not the code. That is the right way round.
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

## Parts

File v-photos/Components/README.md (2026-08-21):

# Component Photos

Individual photographs of each electronic component used on the robot. These are
referenced by the component tables in the main [README](../../README.md).

<!-- TODO: photograph each component and save it here with these exact filenames,
     so the links in the main README resolve:

       pi3.jpg         Raspberry Pi 3 Model B
       pico.jpg        Raspberry Pi Pico 2 W
       camera.jpg      Camera Module 3
       motor.jpg       GA12-N20 gear motor with encoder
       servo.jpg       MG90S servo
       drv8833.jpg     DRV8833 motor driver
       vl53l0x.jpg     VL53L0X distance sensor
       tca9548a.jpg    TCA9548A I2C multiplexer
       bno085.jpg      BNO085 IMU
       tcs34725.jpg    TCS34725 colour sensor
       mini560.jpg     Mini560 buck converter
       battery.jpg     LiPo battery pack

     A plain background and even lighting is enough. Once a photo is here,
     uncomment the matching line in the main README. -->

Note that the parent folder [`v-photos/`](../) is for photographs of the assembled
vehicle from all six sides, which is a separate requirement.

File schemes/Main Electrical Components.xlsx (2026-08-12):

S. No. | Component | Qty (Our Build) | Dimensions (L x W x H mm) | Note
1 | Raspberry Pi 5 | 1 | 85 x 56 mm (board) | Main compute — vision, navigation, orchestration
2 | Raspberry Pi Pico 2 W | 1 | 51 x 21 mm | Real-time controller — sensors, PWM, encoders, safety interlocks
3 | Raspberry Pi Camera Module 3 | 1 | 25 x 24 mm (PCB), ~11.5 mm tall | 12MP autofocus, connects directly to Pi 5 CSI port
4 | BNO085 IMU | 1 | 25.6 x 22.7 x 4.6 mm | 9-DOF orientation sensing
5 | TCS34725 Color Sensor | 1 | ~20.3 x 17.8 mm | RGB + Clear, ground-facing track color detection
6 | VL53L0X ToF Distance Sensor | 4 | 15 x 12 mm | 30-2000mm range, +/-3-10% accuracy
7 | TCA9548A I2C Multiplexer | 1 | 31 x 21 mm | 8-channel I2C mux, 6 of 8 channels used
8 | GA12-N20 Gearmotor w/ Encoder (6V 300RPM) | 1 | 24 x 10 x 11 mm | 300RPM no-load, magnetic quadrature encoder
9 | DRV8833 Motor Driver | 1 | 18 x 21 mm | Dual H-bridge, drives rear motor(s)
10 | MG90S Servo | 1 | 22.8 x 12.2 x 28.5 mm | Metal gear, 1.8-2.2 kg-cm torque
11 | Buck Converter (Mini560) | 1 | ~22 x 17 mm | Adjustable step-down to the regulated 5V rail
12 | LiPo Battery 7.4V 2S | 1 | 74 x 34 x 17 mm | 7.4V 2S — capacity varies by source (see notes)

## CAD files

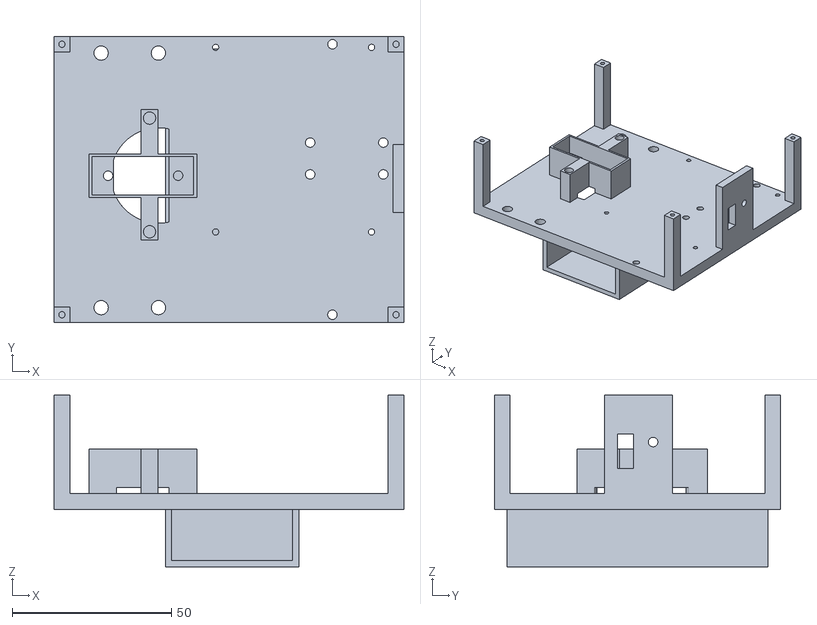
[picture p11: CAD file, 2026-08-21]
models/body/back_down/back down.stl
110.0 x 90.0 x 54.0

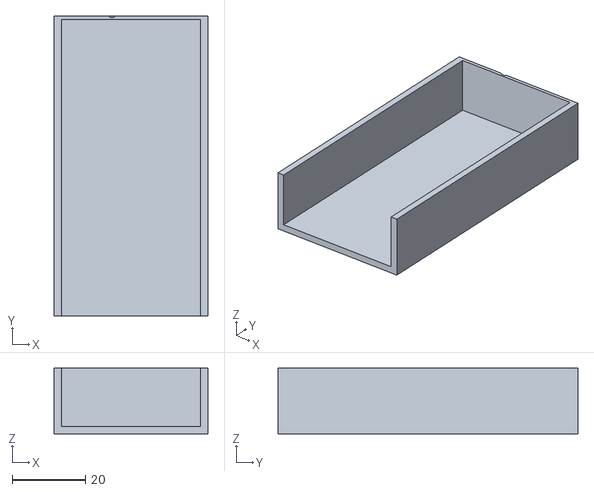
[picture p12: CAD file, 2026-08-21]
models/body/battery_mount/battery_mount.stl
42.0 x 82.0 x 18.0

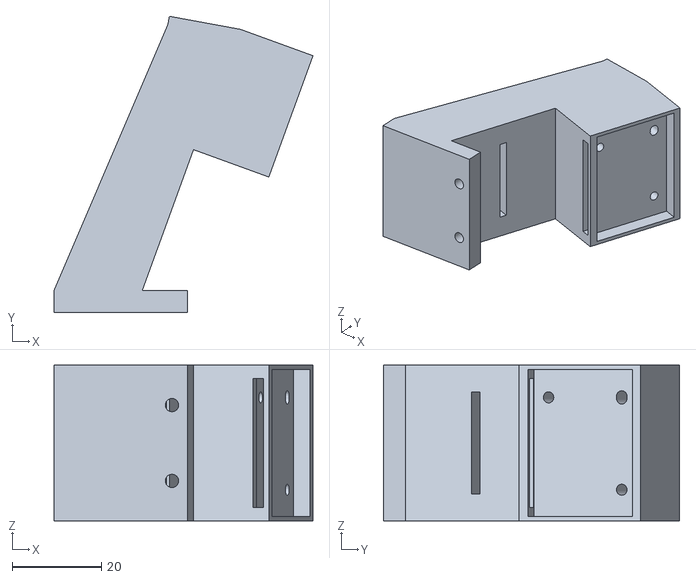
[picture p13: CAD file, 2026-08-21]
models/body/camera_mount/camera_mount.stl
58.2 x 66.6 x 35.0

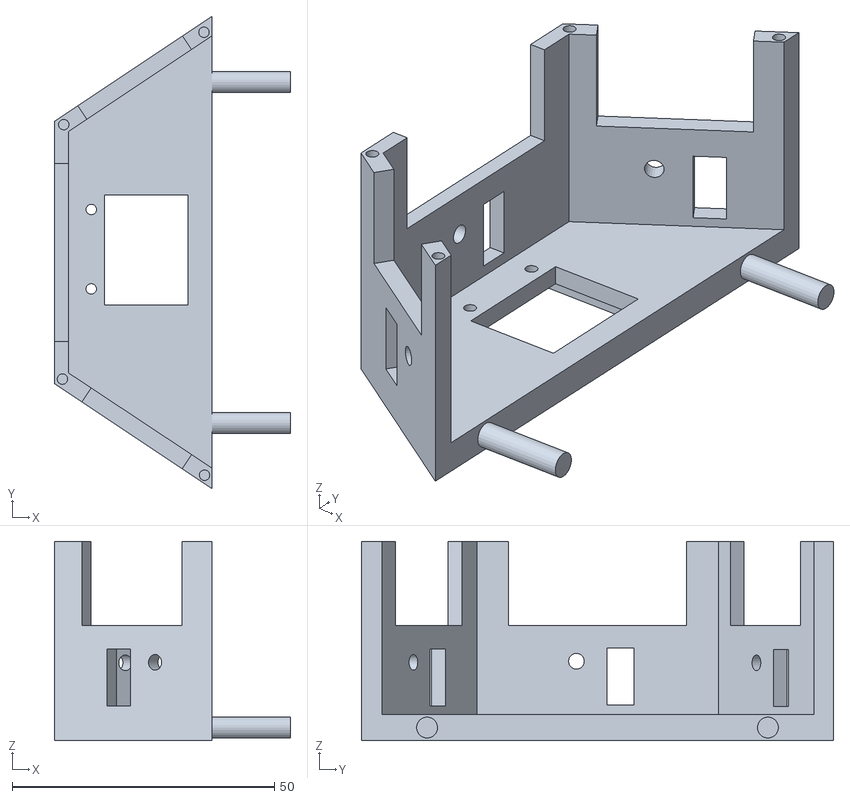
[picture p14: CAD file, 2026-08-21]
models/body/front_down/front down.stl
45.0 x 90.0 x 38.0

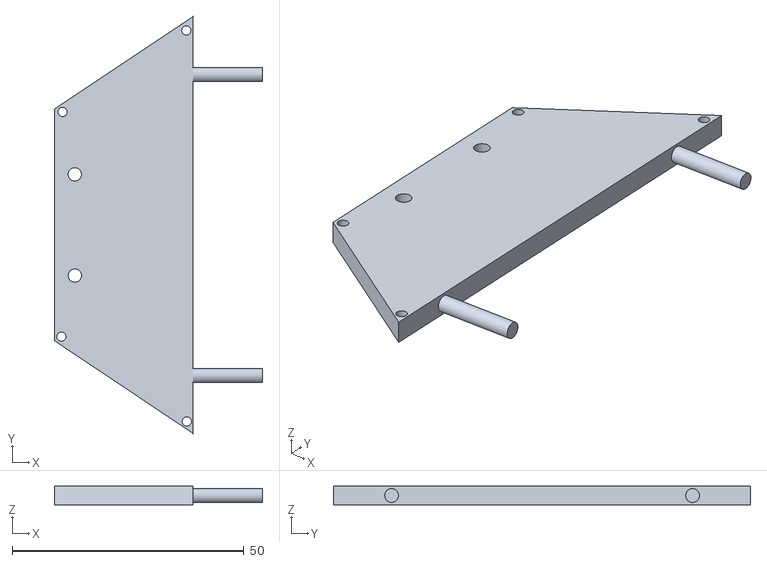
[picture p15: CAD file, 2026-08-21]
models/body/front_top/front top.stl
45.0 x 90.1 x 4.00

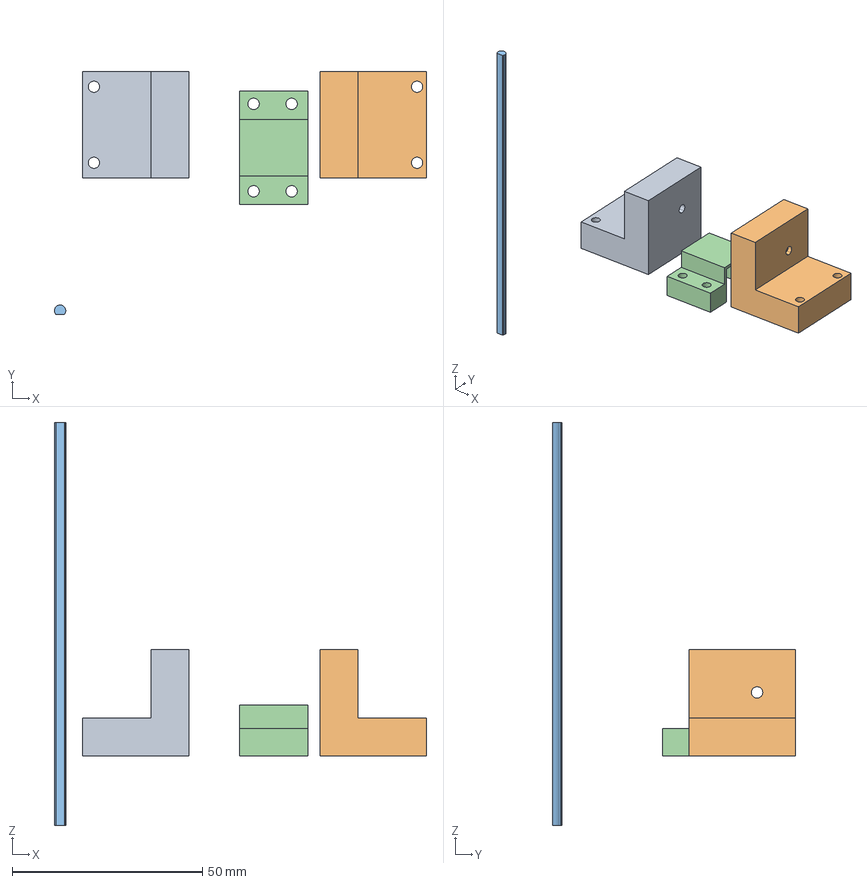
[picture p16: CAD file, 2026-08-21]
models/rear-drive/rear_motor_mount.step
97.9 x 63.9 x 106.0 mm

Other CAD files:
models/front-steering/Ackerman System vinfinity.f3d
models/wheels/wheels.f3d

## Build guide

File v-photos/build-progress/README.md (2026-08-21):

# Build Progress Photos

Photographs taken while the robot was being built, rather than of the finished thing.

## Why this folder exists

Documentation is judged partly on whether the engineering process is visible. A photo
of a finished robot proves the robot exists. A photo of the third version of a bracket
next to the first two proves that a design process happened, and that is a different
and more valuable claim.

Failed attempts are worth more here than successful ones.

## What is worth photographing

<!-- TODO: add photos here. Anything from this list is worth keeping: -->

- The chassis at each stage, especially before it worked
- Prints that failed, warped or did not fit, next to the version that did
- The first wiring attempt, loose wires and all, alongside the finished PCB
- Soldering in progress
- The steering linkage during assembly
- The robot on the bench with test equipment attached
- Anything that broke
- The team actually working, not posed

## Naming

Dated names sort themselves into order and make the sequence obvious:

```
2026-03-14-first-chassis-print.jpg
2026-03-14-chassis-warped.jpg
2026-04-02-steering-assembly-v2.jpg
```

A one line caption for each, in this README, turns a folder of photos into a record of
what happened.

<!-- TODO: add captions here as photos are added, for example:

| Photo | What it shows |
|---|---|
| `2026-03-14-chassis-warped.jpg` | First chassis print, warped at the corners. Reprinted with a brim. | -->

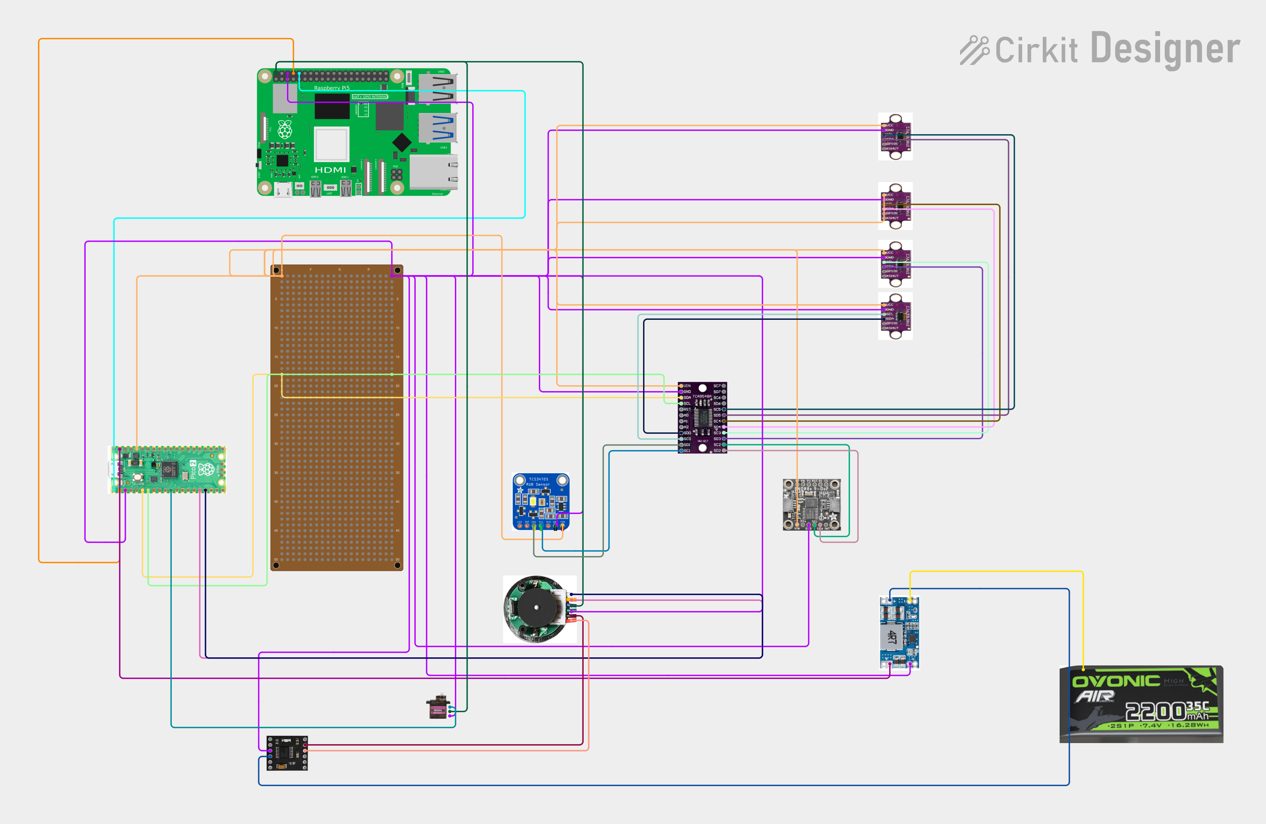
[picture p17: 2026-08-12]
schemes/Wiring_image.png

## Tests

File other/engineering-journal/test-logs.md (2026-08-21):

# Test Logs

Dated records of what was tested, what the numbers were, and what changed as a result.

Fill a row in as soon as a test is run. Reconstructing this later from memory is both
harder and less honest.

---

## Software Self Tests

Every module carries a self test that runs on a laptop with no hardware attached.
Fifteen of the sixteen modules are covered.

| Module | What its test proves |
|---|---|
| Vision | Both colours detected in one frame, noise and wrong shaped blobs rejected, magenta not read as red, parking gap midpoint within one pixel |
| Navigation | Pass side never wrong anywhere in the frame, steering never exceeds the servo limit, rate limit holds, hysteresis works in both directions |
| State machine | Every state has a transition row, no duplicate events, no mission can deadlock |
| Coordinator | Vision output converts correctly, the state machine has the final word on the command |
| Flight program | Wire format verified against the Pi's actual parser rather than a copy of it |
| Servo | Clamping symmetric, pulse always inside safe limits |
| Motor driver | Negative speed means stop rather than reverse, duty monotonic |
| Encoder | One wheel turn equals one circumference, reverse counts negative |
| Distance | One multiplexer bit per channel, other channels never touched |
| IMU | Orientation conversion correct at 0, 90 and 180 degrees |
| Colour | The same surface at half brightness classifies identically |

Run them with `python3 <module>.py --selftest`.

---

## Bench Tests

Wheels off the ground, one subsystem at a time.

<!-- TODO: fill a row in each time you test. Copy the blank row. -->

| Date | Test | Result | Numbers | Action taken |
|---|---|---|---|---|
| | Servo centres straight | | Centre pulse: | |
| | Servo reaches both limits without straining | | Max angle: | |
| | Motor spins in the correct direction | | | |
| | Motor stops from every speed | | | |
| | Lowest speed that moves the robot | | Percent: | |
| | Encoder counts one turn correctly | | Pulses per turn: | |
| | Encoder counts down in reverse | | | |
| | All four distance sensors respond | | | |
| | IMU heading changes correctly when turned | | | |
| | Colour sensor distinguishes mat surfaces | | | |
| | UART survives five minutes under processor load | | | |

---

## Calibration Measurements

The values for this specific build. Every one of these has to be measured, not assumed.

<!-- TODO: fill these in. Each affects something downstream, noted in the last column. -->

| Value | Measured | Affects |
|---|---|---|
| Gear ratio | | Every distance the robot calculates |
| Wheel diameter, under load | | Every distance the robot calculates |
| Servo centre pulse width | | Whether the robot drives straight |
| Maximum usable steering angle | | Turning radius, and whether the servo strains |
| Camera field of view | | Distance estimates to signs and markers |
| Camera height above the mat | | How early signs are seen |
| Red hue range, on the mat | | Whether red signs are detected |
| Green hue range, on the mat | | Whether green signs are detected |
| Magenta hue range, on the mat | | Whether the parking slot is found |
| Battery run time under load | | How many practice runs per charge |

---

## Field Tests

Full runs on a mat.

<!-- TODO: one row per session. Record failures in as much detail as successes,
     they are the rows that tell you what to fix. -->

| Date | Round | Runs | Completed | What failed | What we changed |
|---|---|---|---|---|---|
| | Open | | | | |
| | Obstacle | | | | |
| | Parking | | | | |

---

## Reliability Runs

Once the robot completes a round, repeat it. A robot that works once is not the same as
a robot that works.

<!-- TODO -->

| Date | Round | Attempts | Successes | Success rate | Notes |
|---|---|---|---|---|---|
| | | | | | |

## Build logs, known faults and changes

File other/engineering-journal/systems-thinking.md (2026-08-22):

# Systems Thinking

How the subsystems work together, and what happens at the boundaries between them.

Covers rubric criterion 4, alongside [design-decisions.md](design-decisions.md) for
constraints, trade-offs and risk, and [iteration-log.md](iteration-log.md) for the
testing cycles.

## Subsystem Map

```mermaid
flowchart LR
    subgraph SENSE
        CAM[Camera]
        TOF[4x VL53L0X]
        IMU[BNO085]
        COL[TCS34725]
        ENC[Encoder]
    end
    subgraph THINK
        VIS[Vision]
        NAV[Navigation]
        SM[State machine]
        MM[Mission manager]
    end
    subgraph ACT
        MC[Motion controller]
        SRV[Servo]
        MOT[Motor]
    end

    CAM --> VIS
    VIS --> NAV
    TOF --> SMGR[Sensor manager]
    IMU --> SMGR
    COL --> SMGR
    ENC --> SMGR
    SMGR -->|UART| NAV
    SMGR -->|UART| SM
    MM --> NAV
    MM --> SM
    NAV -->|requested command| SM
    SM -->|final command, UART| MC
    MC --> SRV
    MC --> MOT
    MOT --> ENC
```

Note the loop at the bottom. The motor drives the wheels, the wheels turn the encoder,
the encoder reports back, and that is how the robot knows whether its own command
actually did anything. Without it, stall detection is impossible.

## How Each Pair Interacts

| From | To | What crosses | Why it is shaped that way |
|---|---|---|---|
| Camera | Vision | Raw frame | |
| Vision | Navigation | A list of signs with colour, position and distance | A list rather than one sign, so navigation can choose which matters |
| Sensors | Sensor manager | Individual readings | Each may be `None` independently |
| Sensor manager | Pi | One text line over UART | Plain text so it can be read with any serial terminal when debugging |
| Mission manager | Navigation and state machine | One string | Asked every frame, so automatic detection can replace it later |
| Navigation | State machine | A requested speed and steering | A request, not an instruction |
| State machine | Motion controller | The final command | The only command that reaches the wheels |
| Motion controller | Servo and motor | Duty values | Each device's own module owns its clamping |
| Motor | Encoder | Physical rotation | Closes the loop |

## The Three Boundaries That Matter Most

### Navigation to state machine: request versus authority

Navigation decides **how** to drive. The state machine decides **what** we are doing, and
may only restrain navigation's request, never invent one.

This split exists because the two questions have different answers at different rates.
How to steer around a sign changes every frame. Whether we are avoiding a sign at all
changes every few seconds.

Merging them was our first design, and it produced code where a change to cornering
accidentally affected sign avoidance, because both lived in the same conditionals.

### Pi to Pico: the timing boundary

This is the most important boundary in the system, and it is drawn on timing rather than
on function.

The Pi can pause. Linux may stall a loop for tens of milliseconds. The Pico cannot pause,
because nothing else is running on it.

Everything with a deadline is therefore on the far side of that boundary: PWM
generation, encoder counting, and the safety stop. The consequence is that **the Pi
crashing does not mean the robot keeps driving**, because the thing that stops it lives
on the other board.

### Vision to navigation: units and coordinates

Vision works in centimetres and pixels. Navigation works in millimetres and a normalised
frame offset from -1 to +1.

The conversion happens once, explicitly, in `main.py`. Neither module guesses. Unit
mismatches across a module boundary are a classic way to lose a robot, and the fix is to
make the boundary the only place a conversion happens.

## Failure Propagation

What we designed so that one subsystem failing does not take the others with it.

| If this fails | What happens | What does not happen |
|---|---|---|
| One distance sensor | That reading is `None`, navigation slows | The other three keep working |
| The camera | No signs detected, robot follows the lane | It does not stop or crash |
| The IMU | Corners complete on timeout instead of heading | Driving continues |
| One sensor driver file missing | That sensor reports itself by name | The other five keep working |
| The Pi | Watchdog stops the robot after 500 ms | It does not drive on uncommanded |
| The serial link | Robot stops, Pi keeps retrying | The program does not exit |
| A camera frame | Skipped | The loop does not stall |

The pattern throughout: **degrade rather than stop, and never stop silently.**

## Where the Subsystems Fought Each Other

Three cases where two individually correct subsystems produced a wrong outcome together.
These are the interactions that only appear once things are integrated.

**Emergency stop against cornering.** Navigation stops for a close wall. The state
machine turns towards a wall during a corner. Together, the robot froze mid corner, the
turn never completed, and it timed out into a recovery that could not clear. Fixed with a
minimum speed for the cornering state.

**Emergency stop against parking.** The same shape of problem. The parking trigger sat
at 120 mm but the emergency stop fired at 150 mm, so the robot could never physically
reach its own trigger. Fixed with a minimum speed and a threshold below the stop line,
plus an assertion that enforces the ordering.

**Vision against parking.** Red detection and magenta detection overlapped on the hue
circle, so the parking lot was seen as one enormous traffic sign and the robot tried to
pass it on the right. Fixed by narrowing the red band.

None of these were visible in any single module. All three needed the modules running
together.

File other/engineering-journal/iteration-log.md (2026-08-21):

# Iteration Log

Problems we hit, what actually caused them, and what we changed. Ordered roughly as
they happened.

The pattern worth noticing is how often the visible symptom pointed somewhere other
than the real cause.

---

**Only one of two traffic signs was detected**

*Symptom.* With a single sign on the mat, detection was perfect. With two, one of them
was frequently missed, seemingly at random.

*Cause.* Our saturation and brightness floors were set too high. Two signs on a mat are
never lit equally, and the one further from the lights fell below the threshold. It
looked random because it depended on where the robot happened to be standing.

*Fix.* Floors lowered substantially. A sign in shadow is much darker than one under the
lights, and a high floor silently discards it rather than reporting a problem.

---

**The robot clipped signs it had already passed**

*Symptom.* The robot would steer correctly around a sign, then swing back and catch it
with the rear of the chassis.

*Cause.* Once the sign was cleared to one side, the steering calculation produced a
small correction back towards it.

*Fix.* Clamped the pass direction per colour, so a red sign can only ever produce right
steering and a green one only left.

---

**The robot drifted further off centre with each sign**

*Symptom.* First sign passed cleanly. Second slightly awkwardly. Third ended with the
robot against a wall.

*Cause.* Nothing brought the robot back to the lane centre after a pass. Each avoidance
left it offset, and the offsets accumulated.

*Fix.* Added a dedicated recentre phase that ignores signs and tracks the lane centre
until the robot is back on line.

---

**The robot gave up in the middle of a corner**

*Symptom.* Robot enters a corner, stops facing the wall, waits, then abandons the run.

*Cause.* This one took a while. Turning towards a wall means the front distance sensor
keeps closing, which triggered the emergency stop. But a stopped robot stops turning, so
the corner never completed, so the state timed out into recovery, and recovery could not
clear either because the wall was still there. A chain of individually correct
behaviours producing a dead end.

*Fix.* A minimum speed for the cornering state, so the robot creeps through rather than
freezing. The wall ahead during a corner is the wall being turned away from.

---

**Parking finished on a timer rather than on arrival**

*Symptom.* The robot parked, but always after exactly the same number of seconds,
regardless of where it actually was.

*Cause.* The stop condition watched the rear distance sensor. But the camera faces
forward, so the slot is only visible while driving towards it, meaning the robot enters
nose first. The rear sensor was pointed back at the open mat it had come from and never
triggered.

*Fix.* Watch the front sensor instead, and only while parking, since a close wall
anywhere else on the track means something different.

---

**The parking stop was physically unreachable**

*Symptom.* After the previous fix, the robot stopped short of the slot.

*Cause.* Navigation performs an emergency stop at 150 mm, but the parking trigger sat at
120 mm. The robot froze before it could ever reach its own trigger.

*Fix.* A minimum speed for the entry phase, and a threshold set below the emergency stop
line. We also added an automatic check that enforces that ordering, so if either number
is changed carelessly in future the mistake is caught immediately rather than on the
mat.

---

**The encoder would have destroyed the microcontroller**

*Symptom.* None. This was caught reviewing the connection list, not from behaviour.

*Cause.* The encoder was on the 5 V rail, and a magnetic encoder outputs at whatever
voltage supplies it. That would have put 5 V into pins rated for 3.3 V.

*Fix.* Moved to the 3.3 V rail. Recorded in full in [design-decisions.md](design-decisions.md).

---

**Magenta parking markers were read as red traffic signs**

*Symptom.* The robot treated the parking lot as a giant traffic sign and tried to pass
it on the right.

*Cause.* Magenta sits immediately below red on the hue circle, and our red range started
low enough to swallow it entirely.

*Fix.* Narrowed the red range so it starts higher. This costs nothing, because red's
main band sits at the other end of the hue scale.

---

**Speed flapped between cruise and slow**

*Symptom.* Approaching a wall, the robot audibly surged and slowed several times a
second.

*Cause.* A single distance threshold with a slightly noisy sensor reading. Readings
either side of the threshold flipped the mode on alternate frames.

*Fix.* Hysteresis. Separate thresholds for entering and leaving the slow state, so a
reading hovering near the boundary no longer causes a change.

---

**Stall detection never fired**

*Symptom.* The robot could be held stationary indefinitely without noticing.

*Cause.* The timer that tracks how long the robot has been stalled treated a timestamp
of zero as "not set", so at the very start of a run it reset itself every frame.

*Fix.* An explicit check for whether the value was set, rather than relying on whether
it was non-zero. Worth recording because it would only ever have shown up in the first
seconds of a run.

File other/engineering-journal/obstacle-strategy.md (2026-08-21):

# Obstacle Strategy

How the robot decides which way to go around a traffic sign.

## The Rule

Red signs are passed on their right. Green signs are passed on their left. Getting this
backwards is worse than not seeing the sign at all, because the robot then steers
deliberately into the thing it was meant to avoid.

## One Calculation, Not Nine Cases

The obvious way to write this is a set of cases: red on the left, red in the centre,
red on the right, then the same three for green. That is nine branches once you include
"no sign", and every one of them is a place to make a mistake.

Instead, each colour is given a **target position in the camera frame**.

Passing a red sign on its right means the sign has to end up on the robot's **left**, so
the target for red is a position well to the left of frame centre. Green is the mirror
image. The robot then steers by however far the sign currently is from where it should
be.

That single rule produces all of the behaviour below, with no special cases at all.

| Red sign position in frame | What the robot does |
|---|---|
| Far left | Nothing. It is already clear. |
| Just left of centre | Nothing. It has just cleared. |
| Dead centre | Firm right. This is the dangerous position, because the robot is aimed straight at it. |
| Right of centre | Harder right. |
| Far right | Full lock right. This is the worst case, because the sign is on the wrong side entirely. |

Note that a centred sign produces a strong correction while a sign far to one side
produces none. That is the opposite of what a naive "steer away from the obstacle"
rule would do, and it falls out of the target position idea without being written
anywhere as a special case.

## One Safety Clamp

A red sign may only ever produce right steering, and a green sign may only ever produce
left steering.

Without this, a sign already cleared to the left would produce a small correction back
towards the thing the robot just avoided. That is how you clip one.

## Choosing Between Two Signs

Both colours are often visible at once, typically a red one close and a green one
further down the track.

The **nearer** sign is the one about to be hit, so that is the one the robot steers
around. The far one is handled on later frames, once it has become the near one.

Where the vision module has measured a distance, we rank by that. Where it has not, we
fall back to apparent size, since a nearer sign of the same real size looks bigger. The
order signs happen to appear in the detection list makes no difference to the outcome.

## The Four Phase Pass

A pass is not a single decision. The robot moves through four phases:

`FOLLOW_COURSE` then `APPROACH_PILLAR` then `PASS_PILLAR` then `RECENTER` then back to
`FOLLOW_COURSE`.

**Approach** begins as soon as a sign is seen and is far enough away to line up gently.
Speed drops here, because a slower approach makes the correction smaller.

**Pass** begins once the sign is close, and commits to the path even as the sign drifts
towards the edge of the frame and eventually out of it.

**Recentre** is the phase that stops the robot living permanently offset, and it is the
one we did not have at first. Our early version steered around a sign and simply carried
on. Each obstacle left the robot a little further from the lane centre than the last,
and three signs later it clipped a wall. Now, once the sign has been out of view for
half a second, steering ignores signs entirely and tracks the lane centre until the
offset is back inside a dead zone.

There is a deliberate asymmetry in this sequence. The passing phase has **no route into
recovery**. Losing sight of a sign you are squeezing past is exactly what success looks
like, so both of its exits lead to recentring instead.

## Edge Cases

Each of these came from watching the robot behave oddly, not from planning ahead.

| Case | How it is handled |
|---|---|
| Sign flickers out for a single frame | Half a second of confirmation before the pass is declared over |
| Two signs in view at once | Nearest by measured distance wins, and frame order is irrelevant |
| Sign appears in the middle of a corner | The corner outranks the sign, because the transition table row order says so |
| Blob smaller than the minimum area | Treated as noise, not as a sign |
| Sign jittering around the frame centre | A dead zone snaps it to exactly centred, so the wheels do not twitch |
| A distance sensor returns no reading | Speed drops to slow rather than cruising blind |
| Nothing detected at all | Lane following from the two diagonal sensors |
| A red jacket in the audience | Fill ratio test rejects it. A real sign fills its bounding box; a person does not. |

## What Still Needs Field Testing

<!-- TODO: fill in once the robot has run on a real mat -->

- The steering gain, which controls how hard the robot corrects
- The distance at which the approach phase begins
- Whether half a second is the right confirmation delay for a lost sign
- Behaviour when two signs of the same colour appear in sequence

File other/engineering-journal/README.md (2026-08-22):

# Engineering Journal

The record of how this robot was designed, what we decided and why, what went wrong,
and what we measured.

The main [repository README](../../README.md) describes the robot as it is now. This
folder describes how it got that way, which is a different question and the one judges
are actually assessing.

| Document | Contents |
|---|---|
| [Systems Thinking](systems-thinking.md) | How the subsystems interact, and where they fought each other |
| [Design Decisions](design-decisions.md) | The constraints we worked inside, the trade-offs we made, and what could go wrong |
| [Obstacle Strategy](obstacle-strategy.md) | How the robot decides which side of a traffic sign to pass, and every edge case it handles |
| [Iteration Log](iteration-log.md) | Every problem we hit, what actually caused it, and what we changed |
| [Test Logs](test-logs.md) | Dated records of what we tested and what the numbers were |

<!-- TODO: this folder should also hold the weekly journal itself, either as a PDF
     or as dated markdown entries. Things worth recording each week:
       - what you set out to do
       - what actually happened
       - photographs, including of things that did not work
       - what you decided to do next, and why -->

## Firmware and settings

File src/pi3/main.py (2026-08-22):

"""Pi 3 coordinator: the only file that knows the modules exist.

    frame -> vision -> pillars ─┐
                                ├─> navigation -> requested command ─┐
    UART  -> robot_state ───────┘                                    │
                                                                     v
                                              state machine -> FINAL command
                                                                     │
                                                          UART ──────┘-> Pico

No navigation logic, no steering maths, no state transitions live here. This
file captures, converts, forwards, and sends - nothing else.

Run:  python main.py                 on the Pi, with the Pico connected
      python main.py --dry-run       laptop: webcam + decisions, no UART
      python main.py --show          draw the camera view (costs frame rate)
      python main.py --debug         one status block per frame
      python main.py --start-now     skip the start countdown
      python main.py --selftest      no camera, no UART
"""

import sys
import time
from pathlib import Path

sys.path.insert(0, str(Path(__file__).parent / "camera_vision"))
import cv2                              # noqa: E402
import mission_manager                  # noqa: E402
import navigation_engine                # noqa: E402
import state_machine                    # noqa: E402
import vision_test                      # noqa: E402

# --- Configuration ----------------------------------------------------------
UART_PORT = "/dev/serial0"      # Pi 3: GPIO14/15. Must resolve to ttyAMA0.
UART_BAUD = 115200              # uart_test_pi.py keeps its own copy on purpose:
                                # it is a standalone bench tool, not a dependency
# State line from the Pico: "S,<front>,<left>,<right>,<rear>,<heading>" in mm
# and degrees. A negative distance means that sensor had no reading. Extra
# fields may be appended later without breaking this parser.
STATE_PREFIX = "S"
STOP_COMMAND = "0,0\n"
STOP_REPEATS = 3                # a stop is worth sending more than once
RECONNECT_INTERVAL_S = 1.0      # how often to retry a dropped UART link
LINK_SETTLE_S = 2.0
START_DELAY_S = 3.0             # countdown after launch, so the robot can be
                                # placed. Replace with a real start button on
                                # the Pico when one is wired.
SLOW_FRAME_WARN_S = 0.20        # a frame slower than this risks tripping the
                                # Pico's 500 ms command watchdog
CM_TO_MM = 10
FPS_SMOOTHING = 0.9

DEBUG = False


# --- Conversions ------------------------------------------------------------
def pillars_from_vision(seen):
    """vision_test.detect() output -> the pillar list navigation expects.

    Only the coloured pillars come through; a wall is not something you pass on
    a side, so navigation never sees it.
    """
    pillars = []
    for colour, info in seen.items():
        if colour not in navigation_engine.PASS_TARGET:
            continue
        width, height = info["box"][2], info["box"][3]
        pillars.append({
            "colour": colour,
            "x": info["cx"],
            "area": width * height,
            "distance": info["distance"] * CM_TO_MM,    # vision works in cm
        })
    return pillars


def parse_state(line):
    """A state line from the Pico -> robot_state dict, or None if it is junk."""
    try:
        fields = line.strip().split(",")
        if fields[0] != STATE_PREFIX:
            return None
        front, left, right, rear = (int(value) for value in fields[1:5])
        heading = float(fields[5]) if len(fields) > 5 else None
    except (ValueError, IndexError):
        return None

    def known(value):
        return None if value < 0 else value

    return {"front_distance": known(front), "left_distance": known(left),
            "right_distance": known(right), "rear_distance": known(rear),
            "heading": heading}


# --- UART -------------------------------------------------------------------
def open_link(dry_run):
    """Open the Pico link, or None if we are running without one."""
    if dry_run:
        return None
    import serial
    link = serial.Serial(UART_PORT, UART_BAUD, timeout=0)
    time.sleep(LINK_SETTLE_S)       # let the port settle before the first command
    return link


def read_state(link, previous):
    """Newest state the Pico has sent, or the previous one if it sent nothing.

    Drains the buffer rather than reading a single line, so a slow frame never
    leaves us acting on stale distances.
    """
    if link is None:
        return previous
    state = previous
    while link.in_waiting:
        parsed = parse_state(link.readline().decode(errors="ignore"))
        if parsed:
            state = parsed
    return state


# --- Debug ------------------------------------------------------------------
def debug_block(behaviour, navigation, robot_state, pillars, fps):
    """One compact status block per frame - the only printing in the file."""
    pillar = pillars[0]["colour"] if pillars else "NONE"
    heading = robot_state.get("heading")
    front = robot_state.get("front_distance")
    print("Mission: %s\n"
          "State: %s\n"
          "Detected Pillar: %s\n"
          "Front Distance: %s\n"
          "Heading: %s\n"
          "Speed: %d\n"
          "Steering: %+d\n"
          "Reason: %s\n"
          "FPS: %.1f\n%s"
          % (behaviour["mission"], behaviour["state"], pillar,
             "%d mm" % front if front is not None else "UNKNOWN",
             "%.1f deg" % heading if heading is not None else "UNKNOWN",
             behaviour["speed"], behaviour["steering"],
             navigation["reason"], fps, "-" * 40))


def overlay(frame, seen, behaviour):
    for colour, info in seen.items():
        vision_test.draw(frame, colour, info)
    cv2.putText(frame, "%s  speed %d  steer %+d"
                % (behaviour["state"], behaviour["speed"], behaviour["steering"]),
                (10, 25), cv2.FONT_HERSHEY_SIMPLEX, 0.7, (255, 255, 255), 2)


# --- Main loop --------------------------------------------------------------
def main(dry_run=False, show=False, debug=False, start_delay=START_DELAY_S):
    camera = cv2.VideoCapture(vision_test.CAMERA_INDEX)
    camera.set(cv2.CAP_PROP_FRAME_WIDTH, vision_test.FRAME_WIDTH)
    camera.set(cv2.CAP_PROP_FRAME_HEIGHT, vision_test.FRAME_HEIGHT)
    camera.set(cv2.CAP_PROP_BUFFERSIZE, 1)
    if not camera.isOpened():
        sys.exit("Could not open camera %s" % vision_test.CAMERA_INDEX)

    import serial                       # for the exception type, even in dry run
    try:
        link = open_link(dry_run)
    except serial.SerialException as error:
        sys.exit("Could not open %s: %s\nUse --dry-run to test without the Pico."
                 % (UART_PORT, error))

    navigation_engine.reset()
    state_machine.DEBUG = debug     # one flag, so state changes print with everything else
    machine = state_machine.StateMachine()

    # The robot must not drive off the moment the program launches. Until a
    # start button exists on the Pico, this countdown is the start signal.
    for remaining in range(int(start_delay), 0, -1):
        print("Starting in %d..." % remaining)
        time.sleep(1)
    machine.start()

    robot_state = {}
    mission = None
    next_reconnect = 0.0
    last_frame_at = time.monotonic()
    fps = 0.0
    print("Running%s. Ctrl-C to stop." % (" (dry run, no UART)" if dry_run else ""))

    try:
        while True:
            # 1. capture. A dropped frame is normal - skip it and try again.
            captured, frame = camera.read()
            if not captured:
                continue

            # Keep navigation's idea of the frame width honest, whatever the
            # camera gave us - every pillar offset is measured against it.
            width = frame.shape[1]
            if navigation_engine.CAMERA_WIDTH != width:
                navigation_engine.CAMERA_WIDTH = width
                navigation_engine.CAMERA_CENTRE_X = width // 2

            # 2. see what is there, in the shape the rest of the stack wants
            seen, _, walls = vision_test.detect(frame)
            # The wall is not a pillar, but the state machine uses it to see a
            # corner coming before the front ToF confirms it.
            vision = {"pillars": pillars_from_vision(seen),
                      "wall_distance": (seen["WALL"]["distance"] * CM_TO_MM
                                        if "WALL" in seen else None),
                      "parking": seen.get("PARKING"),
                      "walls": walls}

            # 3-7. everything below can fail if the Pico link drops
            try:
                # 3. what the robot itself reports
                robot_state = read_state(link, robot_state)

                # 4. which round we are running. Asked every frame, not once at
                # startup, so swapping the constant for automatic detection
                # later needs no change here.
                selected = mission_manager.current_mission()
                if selected["mission"] != mission:
                    mission = selected["mission"]
                    machine.mission = mission
                    print("Mission: %s (%s)" % (mission, selected["reason"]))

                # 5. navigation decides HOW to drive. It is told the current
                # behaviour so it can pick a steering law - follow the pillar,
                # track the lane, turn the corner, or aim at the parking slot.
                navigation = navigation_engine.compute_navigation(
                    vision, robot_state, machine.state.value, mission)

                # 6. the state machine decides WHAT we are doing, and returns
                # the final command - navigation's request, restrained by state
                behaviour = machine.update(vision, robot_state, navigation)

                # 7. one command, one place. Always the state machine's.
                if link:
                    link.write(("%d,%d\n" % (behaviour["speed"],
                                              behaviour["steering"])).encode())

            except (OSError, serial.SerialException) as error:
                # The link went away mid-run. Keep looping and keep retrying:
                # stopping the program would leave the robot uncommanded.
                if link:
                    link.close()
                link = None
                print("UART lost (%s), reconnecting..." % error)

            if link is None and not dry_run and time.monotonic() >= next_reconnect:
                next_reconnect = time.monotonic() + RECONNECT_INTERVAL_S
                try:
                    link = open_link(False)
                    print("UART reconnected")
                except serial.SerialException:
                    pass

            now = time.monotonic()
            frame_time = now - last_frame_at
            if frame_time > SLOW_FRAME_WARN_S:
                # The Pico stops the robot if it hears nothing for 500 ms, and we
                # only send once per frame. Say so rather than stuttering silently.
                print("Slow frame: %.0f ms - watchdog trips above %d ms"
                      % (frame_time * 1000, 500))
            fps = FPS_SMOOTHING * fps + (1 - FPS_SMOOTHING) / max(frame_time, 1e-6)
            last_frame_at = now

            if debug:
                debug_block(behaviour, navigation, robot_state,
                            vision["pillars"], fps)
            if show:
                overlay(frame, seen, behaviour)
                cv2.imshow("main", frame)
                if cv2.waitKey(1) & 0xFF == ord("q"):
                    break

    except KeyboardInterrupt:
        print("\nStopping")
    finally:
        # Whatever happened, the robot must not keep driving.
        if link:
            for _ in range(STOP_REPEATS):
                link.write(STOP_COMMAND.encode())
            link.close()
        camera.release()
        cv2.destroyAllWindows()


def selftest():
    state_machine.DEBUG = False

    # --- vision output converts to pillars ---
    seen = {
        "RED": {"cx": 410, "cy": 300, "box": (380, 250, 60, 140), "distance": 60.3},
        "GREEN": {"cx": 170, "cy": 320, "box": (150, 280, 40, 90), "distance": 140.0},
        "WALL": {"cx": 320, "cy": 200, "box": (0, 180, 640, 56), "distance": 95.0},
    }
    pillars = pillars_from_vision(seen)

    # the wall is not a pillar and must never reach navigation
    assert {p["colour"] for p in pillars} == {"RED", "GREEN"}, pillars
    red = next(p for p in pillars if p["colour"] == "RED")
    assert red["x"] == 410 and red["area"] == 60 * 140
    assert red["distance"] == 603                   # cm -> mm
    assert pillars_from_vision({}) == []

    # --- state lines from the Pico ---
    state = parse_state("S,480,230,260,900,91.3\n")
    assert state["front_distance"] == 480 and state["heading"] == 91.3
    assert parse_state("S,480,-1,260,900,91.3")["left_distance"] is None
    assert parse_state("S,480,230,260,900")["heading"] is None
    assert parse_state("S,480,230,260,900,91.3,7,1")["front_distance"] == 480
    for junk in ("", "hello", "S", "S,480", "S,a,b,c,d", "45,23", "\n"):
        assert parse_state(junk) is None, junk
    assert read_state(None, {"front_distance": 500}) == {"front_distance": 500}

    # --- one frame end to end, with no hardware anywhere ---
    clock = [0.0]

    def one_frame(machine, pillars, robot_state, step=0.1, parking=None):
        """One pass of the real loop, in the real order, on a clock we control."""
        clock[0] += step
        vision = {"pillars": pillars, "wall_distance": None,
                  "parking": parking, "walls": None}
        mission = mission_manager.current_mission()["mission"]
        machine.mission = mission
        navigation = navigation_engine.compute_navigation(
            vision, robot_state, machine.state.value, mission)
        return machine.update(vision, robot_state, navigation, now=clock[0])

    clear = {"front_distance": 900, "heading": 0.0, "speed": 40.0,
             "left_distance": 600, "right_distance": 600}
    navigation_engine.reset()
    machine = state_machine.StateMachine()
    machine.start()
    machine.update(None, clear, {"speed": 0}, now=clock[0])             # -> INITIALISE
    clock[0] += state_machine.STATE_TIMEOUT_S[state_machine.State.INITIALISE]
    behaviour = machine.update(None, clear, {"speed": 0}, now=clock[0])
    assert behaviour["state"] == "FOLLOW_COURSE"

    for _ in range(12):
        behaviour = one_frame(machine, pillars, clear)
    # red is the nearer pillar, so we line up to pass it on the right
    assert behaviour["state"] in ("APPROACH_PILLAR", "PASS_PILLAR"), behaviour
    assert behaviour["steering"] > 0, behaviour
    assert behaviour["speed"] > 0

    # once it is gone we recentre rather than driving on permanently offset
    for _ in range(12):
        behaviour = one_frame(machine, [], clear)
    assert behaviour["state"] in ("RECENTER", "FOLLOW_COURSE"), behaviour

    # --- the state machine has the final word on the command ---
    # --- the parking markers reach navigation as a slot to aim at ---
    slot = {"markers": 2, "offset": 0.5}
    machine.state = state_machine.State.ALIGN_PARKING
    parking_frame = one_frame(machine, [], clear, parking=slot)
    assert parking_frame["state"] in ("ALIGN_PARKING", "ENTER_PARKING"), parking_frame
    assert parking_frame["steering"] > 0, parking_frame     # slot is to the right
    assert parking_frame["speed"] == navigation_engine.MISSION_CRUISE_SPEED[
        navigation_engine.MISSION_PARKING], parking_frame

    machine.state = state_machine.State.FINISHED
    vision = {"pillars": pillars, "wall_distance": None,
              "parking": None, "walls": None}
    navigation = navigation_engine.compute_navigation(vision, clear)
    behaviour = machine.update(vision, clear, navigation, now=clock[0])
    assert navigation["speed"] > 0, navigation          # navigation wants to drive
    assert (behaviour["speed"], behaviour["steering"]) == (0, 0), behaviour

    # --- with no state from the Pico at all, we crawl rather than cruise ---
    navigation_engine.reset()
    blind = navigation_engine.compute_navigation({"pillars": []}, {})
    assert blind["speed"] == navigation_engine.SLOW_SPEED, blind

    # --- the mission decides what the same frame means ---
    saved = mission_manager.MISSION
    try:
        red_ahead = [{"colour": "RED", "x": 415, "area": 8200, "distance": 600}]
        outcomes = {}
        for choice in mission_manager.Mission:
            mission_manager.MISSION = choice
            navigation_engine.reset()
            machine = state_machine.StateMachine(choice.value)
            machine.start()
            # through the real entry path, not by forcing a state
            one_frame(machine, [], clear)                      # -> INITIALISE
            one_frame(machine, [], clear,
                      step=state_machine.STATE_TIMEOUT_S[state_machine.State.INITIALISE])
            outcomes[choice.value] = one_frame(machine, red_ahead, clear)["state"]

        # the obstacle round works the pillar; the open round drives past it
        assert outcomes["OBSTACLE_CHALLENGE"] == "APPROACH_PILLAR", outcomes
        assert outcomes["OPEN_CHALLENGE"] == "FOLLOW_COURSE", outcomes
        assert outcomes["PARKING"] == "SEARCH_PARKING", outcomes
    finally:
        mission_manager.MISSION = saved

    print("selftest ok  pillars %s -> state %s, speed %d, steering %+d"
          % ([p["colour"] for p in pillars], behaviour["state"],
             behaviour["speed"], behaviour["steering"]))


if __name__ == "__main__":
    if "--selftest" in sys.argv:
        selftest()
    else:
        main(dry_run="--dry-run" in sys.argv,
             show="--show" in sys.argv,
             debug=DEBUG or "--debug" in sys.argv,
             start_delay=0 if "--start-now" in sys.argv else START_DELAY_S)

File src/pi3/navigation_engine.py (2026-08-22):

"""Navigation Engine: vision + robot state -> one movement command.

    compute_navigation(vision_data, robot_state) -> {"speed", "steering", ...}

Decides only. It never touches a motor or a servo - the command it returns goes
over UART to the Pico, which owns the hardware.

Sign convention, the same one the UART link and the Pico use:
    steering  positive = right, negative = left, 0 = straight
    speed     0 = stopped, 100 = flat out

The steering maths is pure: every function below takes what it needs as an
argument and reads nothing but configuration constants. The only state in the
file is the previous frame's steering and speed mode, held by compute_navigation
so that rate limiting and hysteresis have something to compare against.

Run:  python navigation_engine.py            (demo of the decision table)
      python navigation_engine.py --selftest
"""

import sys

# ============================================================================
# CONFIGURATION - every tunable number in the file lives here
# ============================================================================

# --- Colours ----------------------------------------------------------------
COLOUR_RED = "RED"
COLOUR_GREEN = "GREEN"

# --- Camera -----------------------------------------------------------------
CAMERA_WIDTH = 640
CAMERA_CENTRE_X = CAMERA_WIDTH // 2
MIN_PILLAR_AREA = 500           # px^2. Below this it is noise, not a pillar

# --- Steering ---------------------------------------------------------------
MAX_STEERING_DEG = 30           # matches the servo's mechanical limit
STEERING_GAIN = 30.0            # degrees of steering per unit of offset error
STRAIGHT_STEERING_DEG = 0

# Where a pillar should sit in the frame once we are safely past it. Passing a
# red pillar on its RIGHT means the pillar ends up on our LEFT, i.e. negative.
PASS_TARGET_OFFSET = 0.5
PASS_TARGET = {COLOUR_RED: -PASS_TARGET_OFFSET, COLOUR_GREEN: PASS_TARGET_OFFSET}
# Which way we are allowed to steer for each colour. Red is passed on the right,
# so a red pillar may only ever produce right steering, and vice versa.
PASS_DIRECTION = {COLOUR_RED: 1, COLOUR_GREEN: -1}

# Jitter of a few pixels around the centre should not keep nudging the wheels,
# so an offset this small is treated as exactly centred.
CENTRE_DEAD_ZONE = 0.06
# How far off centre before we call it left or right in the debug output.
POSITION_CENTRE_BAND = 0.15
# Most the steering angle may change between consecutive frames. Lower is
# smoother but slower to react.
STEERING_MAX_CHANGE_DEG = 6

# --- Lane keeping -----------------------------------------------------------
# The left and right ToF sensors sit at +/-45 degrees either side of the camera,
# so they watch the forward diagonals. Comparing the two tells us which side of
# the lane we are on without ever needing to know how wide the lane is.
LANE_GAIN = 22.0            # degrees of steering per unit of lane offset

# Lane position from the camera. Preferred over the distance sensors because it
# arrives with the frame instead of at the end of a 132 ms sensor sweep, and
# because the camera sees ahead, so it starts correcting for a curve before the
# robot reaches it. The sensors remain the fallback when no wall is in view.
WALL_BALANCE_GAIN = 26.0
WALL_BAND_MIN_PIXELS = 60   # below this there is not enough wall to steer by
LANE_DEAD_ZONE = 0.08       # closer to centre than this counts as centred
LANE_MAX_VALID_MM = 2000    # a VL53L0X reports ~8190 mm when it sees nothing

# Modes that change which steering law applies. Anything else follows the
# pillar when one is visible and the lane when one is not.
MODE_TURN_CORNER = "TURN_CORNER"
MODE_RECENTER = "RECENTER"

# --- Missions ---------------------------------------------------------------
# These strings match mission_manager.Mission. They are repeated rather than
# imported so navigation stays free of any dependency on it - the mission
# arrives as an argument, like everything else this module reasons about.
MISSION_OPEN = "OPEN_CHALLENGE"
MISSION_OBSTACLE = "OBSTACLE_CHALLENGE"
MISSION_PARKING = "PARKING"

# Only the obstacle round has pillars to dodge. In the others a red or green
# object is scenery, and swerving at it would be a mistake.
MISSIONS_WITH_PILLARS = (MISSION_OBSTACLE,)

# Behaviours (state machine states) during which we are working a pillar.
MODE_APPROACH_PILLAR = "APPROACH_PILLAR"
MODE_PASS_PILLAR = "PASS_PILLAR"
PILLAR_MODES = (MODE_APPROACH_PILLAR, MODE_PASS_PILLAR)

# Parking happens at the end of three laps, back where the robot started.
MODE_SEARCH_PARKING = "SEARCH_PARKING"
MODE_ALIGN_PARKING = "ALIGN_PARKING"
MODE_ENTER_PARKING = "ENTER_PARKING"
PARKING_MODES = (MODE_SEARCH_PARKING, MODE_ALIGN_PARKING, MODE_ENTER_PARKING)

PARKING_GAIN = 25.0             # degrees of steering per unit of gap offset

# --- Speed ------------------------------------------------------------------
CRUISE_SPEED = 45
SLOW_SPEED = 25
STOP_SPEED = 0

# Cruising speed per mission. The open round has nothing to dodge, so it can
# run harder; parking is a crawl from start to finish.
MISSION_CRUISE_SPEED = {
    MISSION_OPEN: 60,
    MISSION_OBSTACLE: CRUISE_SPEED,
    MISSION_PARKING: 20,
}
PILLAR_APPROACH_SPEED = 30      # slow down while working a pillar

MODE_CRUISE = "CRUISE"
MODE_SLOW = "SLOW"
MODE_STOP = "STOP"

# Hysteresis: each threshold has a lower value to enter the slower state and a
# higher one to leave it. A reading hovering on a single threshold would
# otherwise flip the robot between cruise and slow several times a second.
SLOW_ENTER_MM = 400             # closer than this -> slow down
SLOW_EXIT_MM = 500              # must be clearer than this to speed up again
STOP_ENTER_MM = 150             # closer than this -> stop
STOP_EXIT_MM = 220              # must be clearer than this to move off again

DEBUG = False

# ============================================================================
# PURE FUNCTIONS - no state, no globals beyond the configuration above
# ============================================================================


def normalise_pillars(vision_data):
    """Accept whichever shape the vision module hands over.

    Preferred is a list of pillars, so several can be visible at once:
        {"pillars": [{"colour": "RED", "x": 410, "area": 8200}, ...]}
    A single-pillar dict with largest_colour/center_x/area still works.
    """
    if not vision_data:
        return []
    if isinstance(vision_data, list):
        return vision_data
    if vision_data.get("pillars"):
        return vision_data["pillars"]

    colour = vision_data.get("largest_colour")
    if not colour:
        return []
    return [{"colour": colour,
             "x": vision_data.get("center_x", CAMERA_CENTRE_X),
             "area": vision_data.get("area", 0),
             "distance": vision_data.get("distance")}]
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

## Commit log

2026-08-12 Create Pico
2026-08-21 Rewrite robot software: Pi 3 vision and planning, Pico 2 W control
    Replaces the earlier untested prototype with a tested two-controller stack.
    Raspberry Pi 3 (src/pi3):
    - vision_test.py red/green sign, wall and magenta parking marker detection
    with distance estimation from known object heights
    - navigation_engine.py speed and steering, with separate laws for lane
    following, sign passing, cornering and parking
    - state_machine.py event-driven competition behaviour, 12 states across
    3 missions, transitions held in one readable table
    - mission_manager.py selects Open, Obstacle or Parking challenge
    - main.py coordinator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
    [colour.py, distance.py, drv8833.py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]
2026-08-21 Remove editor config from version control
    .vscode/ holds VS Code settings and Pico deploy shortcuts. Useful
    locally, but machine-specific and not part of the robot, so it is
    now ignored rather than tracked.
2026-08-21 Rewrite schemes README for the Pi 3 architecture
    The document still described a Pi 5 running ROS 2 and SLAM, neither of
    which this robot uses. Rewritten to describe what the two boards
    actually do, with a component list carrying electrical specifications,
    and the robot dimensions removed since they belong in the main README.
2026-08-21 Rewrite main README: team details, components with specifications, 3D models
    Adds real team information, component specifications with an explanation
    of what each part does, and a section covering the printed and machined
    parts with renders from models/. Expands the Ackermann steering
    rationale. Removes the challenge summary, obstacle strategy, systems
    thinking and testing sections.
2026-08-21 Fill in every folder README, add camera mount, rewrite team section
    Writes the previously empty READMEs for models and each part folder, src
    and both board folders, video, other, and the component photo folder.
    Adds the camera mount to the models section of the main README. Rewrites
    the team introductions in full sentences. Replaces component image tags
    with placeholders until the photographs exist, so no broken images are
    shown.
2026-08-21 Add engineering journal, sensor placement diagram, photo folders
    Creates other/engineering-journal/ holding the design decisions, obstacle
    strategy, iteration log and test log templates that were removed from the
    main README.
    Adds schemes/sensor-placement.svg, a scale top down drawing of the six
    sensor positions with their angles and fields of view, linked from both
    the main and schemes READMEs.
    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
2026-08-21 Redraw sensor placement with the trapezoidal nose
    The three front distance sensors sit on the three faces of the
    trapezoidal nose, each perpendicular to its own face, which is what
    produces the 0 and plus or minus 45 degree angles. Removes the note
    box and describes the geometry in both READMEs.
2026-08-22 Move colour sensor to the nose and IMU rearward in the placement drawing
    The colour sensor mounts on the underside of the nose below the camera
    mount, not under the middle of the chassis, and the IMU sits behind the
    drive assembly. Updates the drawing and the placement tables, and
    explains why each position was chosen.
2026-08-22 Add rubric-aligned engineering documentation to each folder
    Each documentation criterion now has a dedicated document beside the work
    it describes:
    models/mechanical-design.md chassis and drivetrain choices, torque and
    speed reasoning, steering justification,
    stability, trade-offs, iterations
    schemes/power-and-sensors.md power architecture and budget, current draw
    reasoning, sensor selection and placement
    justified by field geometry, calibration
    method, failure point analysis
    src/software-architecture.md module structure, c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
2026-08-22 Steer from camera wall balance, with the distance sensors as fallback
    Lane position was measured only from the two 45 degree ToF sensors, which
    are up to a full 132 ms sweep old by the time navigation uses them. The
    camera already produced a wall measurement every frame and it was being
    discarded.
    Vision now counts wall pixels in the outer thirds of the frame and returns
    the normalised balance between them. Navigation prefers that signal and
    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
